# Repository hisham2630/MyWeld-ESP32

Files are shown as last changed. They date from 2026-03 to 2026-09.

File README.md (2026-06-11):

# ⚡ MyWeld ESP32 Firmware

> Supercapacitor spot welder controller firmware for **ESP32-S3** boards — from the **Guition JC3248W535** color touchscreen to **20×4 character LCD** DevKit builds and more.







---

## 📋 Table of Contents

- [Overview](#overview)
- [Hardware](#hardware)
- [Schematic](#-schematic)
- [Architecture](#architecture)
- [Features](#features)
- [Weld Pulse Sequence](#weld-pulse-sequence)
- [BLE Protocol](#ble-protocol)
- [Pin Assignments](#pin-assignments)
- [Supported Boards](#supported-boards)
- [Getting Started](#getting-started)
- [Project Structure](#project-structure)
- [Voice Prompts](#voice-prompts)
- [Configuration](#configuration)
- [Safety Design](#safety-design)
- [Acknowledgments](#acknowledgments)

---

## Overview

**MyWeld** is a DIY supercapacitor spot welder controlled by an ESP32-S3 microcontroller, adapted from the [**MyWeld V2.0 PRO**](https://www.youtube.com/@akakasyan) by **Aka Kasyan**. The firmware provides:

- A full-color touchscreen UI (LVGL 9.x, 480×320) for real-time control and monitoring
- A dual-mode welding engine — **Manual** (button press) and **Auto** (contact detection)
- A **P1 / T / P2 dual-pulse** sequence for professional weld quality
- **BLE companion app** connectivity (Android) via a custom binary protocol
- Up to **10 named presets** stored in NVS (flash)
- **P1/T/P2/P3/P4 quad-pulse** support for advanced weld profiles
- **I2S audio** feedback — TTS voice prompts for boot/BLE, spoken weld warnings, plus tones and melodies with adjustable volume
- Real-time **supercapacitor voltage monitoring** with configurable max voltage (4.0–12.0 V)
- **ADC calibration** system with per-channel correction factors stored in calibration partition

---

## Hardware

| Component | Part |
|---|---|
| **MCU Board** | Guition JC3248W535 (ESP32-S3, 16 MB Flash, PSRAM) |
| **Display** | 3.5″ 480×320 TFT, QSPI, AXS15231B controller |
| **Touch** | Capacitive touch via I2C (addr `0x3B`) |
| **Audio** | Built-in I2S amplifier → speaker (P6 header) |
| **Supercap Bank** | Configurable — supports 4.0–12.0 V (e.g., 2S2P @ 5.7 V or 4S @ 12.0 V) |
| **Gate Driver** | IR4427PBF (half-bridge) or TLP358H(F) (photocoupler) |
| **Output** | MOSFET bank fire signal (`GPIO 46`) |
| **Charger** | Supercap charger enable (`GPIO 16`, active-LOW) |
| **Weld Button** | External trigger (`GPIO 14`, active-LOW, pull-up) |

---

## 🔌 Schematic

Two gate-driver variants are provided — choose the one matching your build:

### Variant A — IR4427 Half-Bridge Gate Driver

<p align="center">
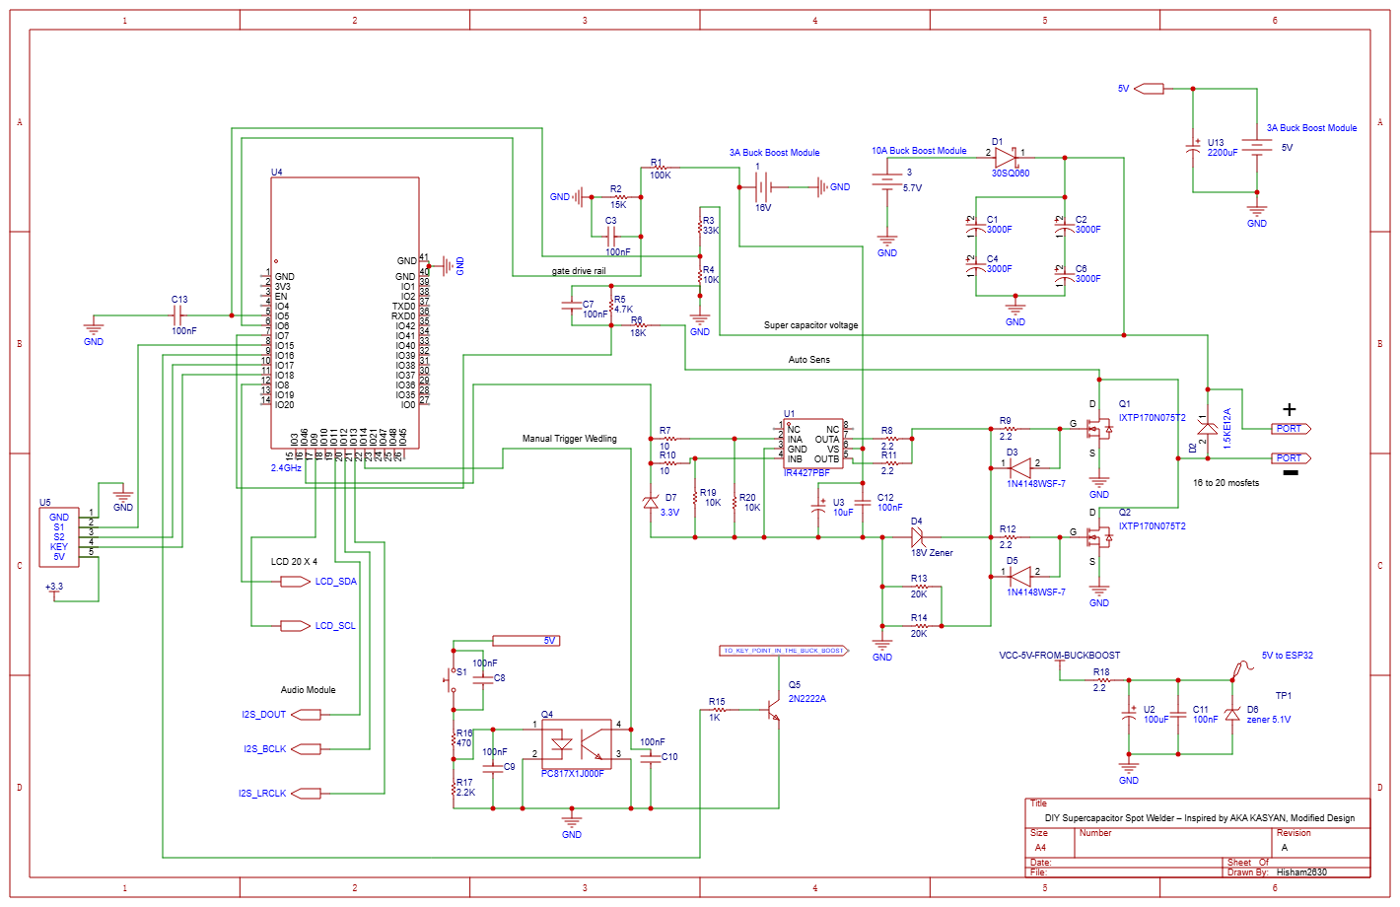
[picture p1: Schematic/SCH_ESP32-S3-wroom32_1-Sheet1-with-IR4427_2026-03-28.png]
MyWeld Schematic — IR4427 Gate Driver
  
</p>

### Variant B — TLP358H(F) Photocoupler Gate Driver

<p align="center">
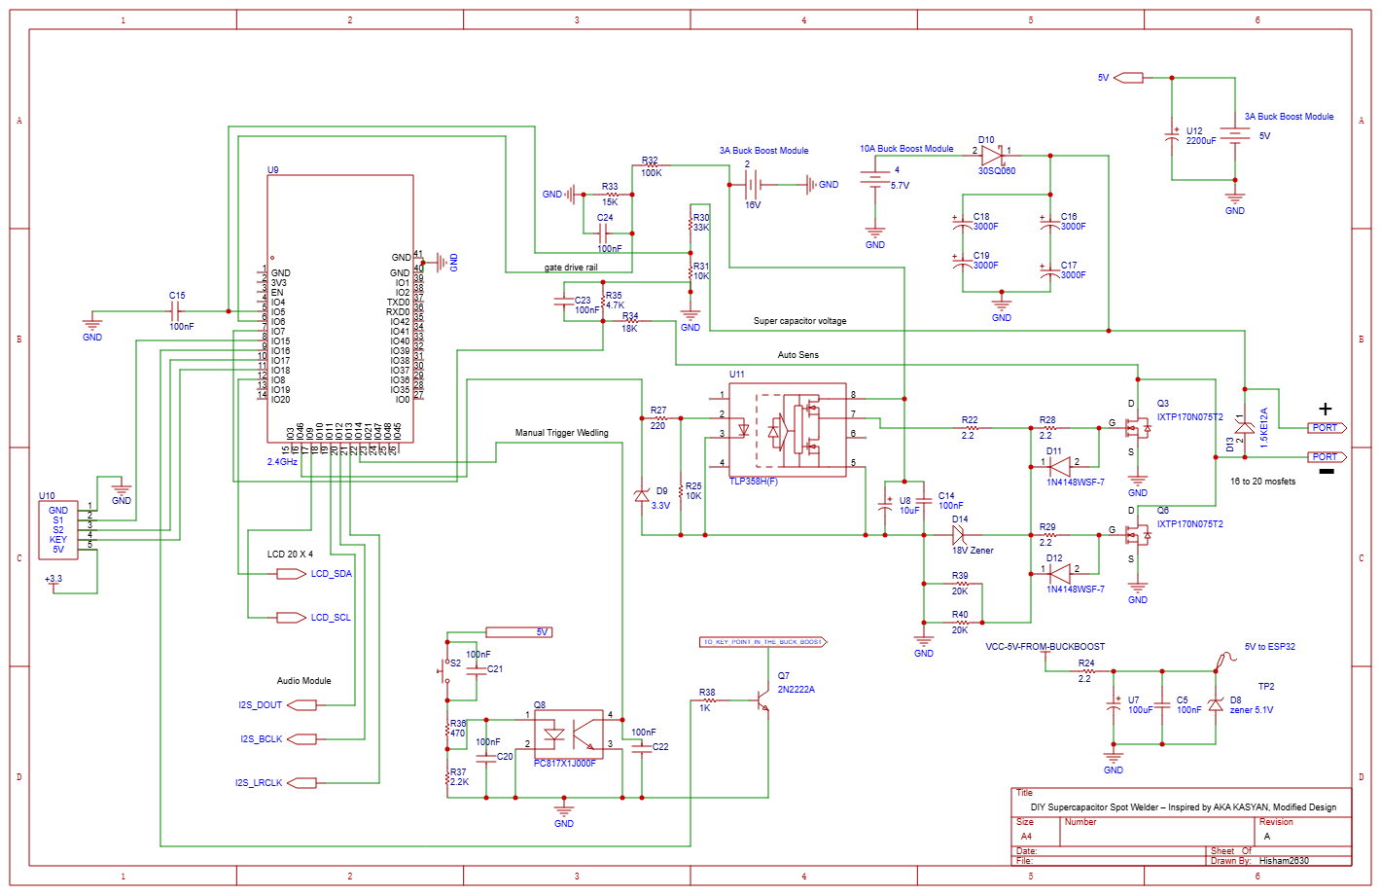
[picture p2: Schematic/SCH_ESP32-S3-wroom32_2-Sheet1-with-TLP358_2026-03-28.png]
MyWeld Schematic — TLP358 Photocoupler
  
</p>

> EasyEDA project files are in the [`Schematic/`](Schematic/) folder.

---

## Architecture

The firmware runs **5 FreeRTOS tasks** pinned to two cores:

```
Core 0                          Core 1
──────────────────────          ────────────────────────────
ui_task      (priority 5)       welding_task  (priority 10)  ← highest
ble_task     (priority 1)       adc_task      (priority  3)
                                audio_task    (priority  2)
```

**Core 0** handles all UI rendering (LVGL) and BLE communication.  
**Core 1** handles time-critical welding pulses, ADC voltage sampling, and audio output.

### Initialization Order (Safety-Critical)

```
1. GPIO safe defaults  ← MOSFET = LOW immediately on boot
2. NVS init           ← Load saved settings / presets
3. I2S audio init
4. Display + LVGL init
5. UI build
6. Welding state machine init
7. BLE serial init
8. Launch FreeRTOS tasks
```

---

## Features

### ✅ Dual Welding Modes

| Mode | Trigger | Description |
|---|---|---|
| **MAN** (Manual) | Physical button (`GPIO 14`) | Press and hold to fire |
| **AUTO** | Electrode contact detection (`GPIO 7`) | Auto-fires after configurable delay `S` |

### ✅ P1/T/P2/P3/P4 Multi-Pulse Sequence

```
[P1] ─ [T] ─ [P2] ─ [T] ─ [P3] ─ [T] ─ [P4]
  │                                        │
0.0–50 ms each         (P2/P3/P4 = 0 → disabled)
```

P3 and P4 are optional additional pulses for advanced weld profiles.

### ✅ Real-Time Status Display

- Supercapacitor voltage bar (0–max V with color coding, configurable max)
- Charge percentage (derived from configurable max voltage)
- Weld state indicator (IDLE / ARMED / FIRING / BLOCKED / ERROR)
- Session and lifetime weld counters
- Active preset name
- Volume level indicator

### ✅ Preset Management

- 20 preset slots — 7 factory (read-only) + 13 user-custom (up to 20 chars each)
- Stores: P1, T, P2, S, mode (AUTO/MAN)
- Instantly loadable from UI or Android app

### ✅ BLE Remote Control

- Device advertises as `"MyWeld"` (configurable display name)
- PIN authentication (default: `1234`)
- Real-time status notifications every ~500 ms
- Read/write all weld parameters remotely
- Load/save presets remotely

### ✅ Audio Feedback

#### Spoken voice prompts (I2S speaker boards)

| Prompt | When |
|---|---|
| **Welcome** | Splash screen phase 1 (boot) |
| **Ready to pair** | Splash finished and BLE advertising |
| **Pairing** | User must enter PIN (1.5 s after connect, or wrong PIN retry) |
| **Device has been connected** | PIN accepted (manual entry or stored PIN auto-auth) |
| **Low charge warning** | Supercap too low to weld |
| **Weak weld warning** | Voltage low but welding still allowed |

Voice clips play first; the startup melody and BLE connect chime still follow where applicable. Buzzer-only boards use distinct tone patterns for the same states.

#### Tones & melodies

| Tone | Event |
|---|---|
| Startup melody (C–E–G) | Boot complete (after welcome voice) |
| Double beep (D5–A5) | BLE authenticated (after connected voice) |
| Single beep (880 Hz) | Parameter changed |
| High beep (1200 Hz) | Pulse fired |
| Error melody | Fault / blocked |
| Contact tone (1000 Hz) | AUTO contact detected |

### ✅ Configurable Supercap Voltage

- Max voltage configurable from **4.0 V to 12.0 V** (step: 0.01 V)
- Stored in calibration partition — survives factory reset
- All thresholds derived automatically:
  - Full = max − 0.2 V
  - Low warning = 70% of max
  - Low block = 50% of max
  - Contact detect = dynamic (based on voltage divider ratio)
- Settable from Android app via BLE calibration command (channel 2)

### ✅ Safety Features

- MOSFET output driven **LOW on boot** before any other init
- Low-voltage block: refuses to weld below **50% of max voltage**
- Low-voltage warning: at **70% of max voltage**
- Charger disabled during pulse (prevents charging during discharge)
- ADC-based protection rail monitoring (gate-drive health check)
- NVS write debouncing (prevents flash wear)
- BLE authentication with **brute-force lockout** (escalating delays)

---

## Weld Pulse Sequence

```
        ┌─ charger OFF ────────────────────────────────────────────────┐
        │  settle 500µs                                                settle 500µs
        │          ┌────┐      ┌────┐      ┌────┐      ┌────┐         │
OUTPUT  │          │ P1 │  T  │ P2 │  T  │ P3 │  T  │ P4 │         │
────────┘          └────┘      └────┘      └────┘      └────┘         └── charger ON
        │←500µs→│← P1→│←T→│← P2→│←T→│← P3→│←T→│← P4→│←500µs→│
```

- **P1**: Pre-pulse (cleans surface, typically 3–8 ms)  
- **T**: Pause between pulses (typically 5–10 ms)  
- **P2**: Main pulse (fuses metal, typically 5–15 ms). Set to 0 for single-pulse mode.
- **P3**: Optional third pulse (set to 0 to disable)
- **P4**: Optional fourth pulse (set to 0 to disable)

---

## BLE Protocol

The firmware uses a custom **binary protocol V2** over BLE GATT.

### GATT Service

| Attribute | UUID |
|---|---|
| Service | `00001234-0000-1000-8000-00805F9B34FB` |
| Params Char (READ) | `00001235-0000-1000-8000-00805F9B34FB` |
| Status Char (NOTIFY) | `00001236-0000-1000-8000-00805F9B34FB` |
| Command Char (WRITE) | `00001237-0000-1000-8000-00805F9B34FB` |

### Packet Format

```
[SYNC=0xAA] [TYPE] [LEN] [PAYLOAD...] [CRC]
                                        └── XOR of TYPE + LEN + all PAYLOAD bytes
```

All multi-byte values are **little-endian**.

### Message Types

| Type | Direction | Description |
|---|---|---|
| `0x01` STATUS | ESP→App | 46-byte periodic status (via NOTIFY, ~500 ms) |
| `0x02` PARAMS_READ | App→ESP | Request current parameters |
| `0x03` PARAMS_RESPONSE | ESP→App | Current parameters (28 bytes) |
| `0x04` PARAMS_WRITE | App→ESP | Update parameters |
| `0x05` CMD | App→ESP | Execute command (sub-typed) |
| `0x06` ACK | ESP→App | Success response |
| `0x07` NAK | ESP→App | Error response |
| `0x08` VERSION | App→ESP | Request firmware version |
| `0x09` VERSION_RESPONSE | ESP→App | Firmware version info |
| `0x0D` AUTH_REQUEST | App→ESP | Authenticate with PIN |
| `0x0E` AUTH_RESPONSE | ESP→App | Authentication result |

### Status Packet (0x01) — 46 bytes

| Offset | Field | Type | Notes |
|---|---|---|---|
| 0 | `supercap_mv` | u16 | Supercap voltage in mV |
| 2 | `protection_mv` | u16 | Gate drive rail in mV |
| 4 | `state` | u8 | Weld state enum |
| 5 | `charge_percent` | u8 | 0–100 % |
| 6 | `auto_mode` | u8 | 0=MAN, 1=AUTO |
| 7 | `active_preset` | u8 | 0–19 (0xFF = user-defined) |
| 8 | `session_welds` | u32 | Session counter |
| 12 | `total_welds` | u32 | Lifetime counter |
| 16 | `ble_connected` | u8 | 1 if BLE connected |
| 17 | `sound_on` | u8 | |
| 18 | `theme` | u8 | 0=dark, 1=light |
| 19 | `error_code` | u8 | 0=none |
| 20 | `p1_x10` | u16 | P1 × 10 (e.g. 50 = 5.0 ms) |
| 22 | `t_x10` | u16 | T × 10 |
| 24 | `p2_x10` | u16 | P2 × 10 |
| 26 | `p3_x10` | u16 | P3 × 10 (0 = disabled) |
| 28 | `p4_x10` | u16 | P4 × 10 (0 = disabled) |
| 30 | `s_x10` | u16 | S × 10 (e.g. 5 = 0.5 s) |
| 32 | `fw_major` | u8 | Firmware major version |
| 33 | `fw_minor` | u8 | Firmware minor version |
| 34 | `volume` | u8 | Master volume 0–100% |
| 35 | `auth_lockout_sec` | u8 | Remaining lockout seconds |
| 36 | `raw_supercap_mv` | u16 | Uncalibrated supercap voltage |
| 38 | `raw_protection_mv` | u16 | Uncalibrated protection voltage |
| 40 | `cal_factor_v_x1000` | u16 | Supercap cal factor × 1000 |
| 42 | `cal_factor_p_x1000` | u16 | Protection cal factor × 1000 |
| 44 | `max_supercap_mv` | u16 | Configured max supercap voltage (mV) |

### Commands (`0x05` CMD sub-types)

| Sub-type | Command |
|---|---|
| `0x01` | Load preset by index |
| `0x02` | Save current params as preset |
| `0x03` | Factory reset |
| `0x04` | Reset weld counter |
| `0x05` | Calibrate ADC (ch0=supercap, ch1=protection, ch2=max voltage) |
| `0x06` | Authenticate (PIN) |
| `0x07` | Change PIN |
| `0x08` | Reboot device |

---

## Pin Assignments

| Function | GPIO | Notes |
|---|---|---|
| MOSFET fire output | 46 | Active HIGH, pull-down |
| Charger enable | 16 | Active LOW |
| Weld button | 14 | Active LOW, pull-up |
| Supercap voltage ADC | 5 | ADC1_CH4, 33k+10k divider |
| Protection rail ADC | 6 | ADC1_CH5, 100k+15k divider |
| Contact detect ADC | 7 | ADC1_CH6, 18k+4.7k divider |
| LCD QSPI CLK | 47 | Internal, no user wiring |
| LCD QSPI CS | 45 | Internal |
| LCD TE | 38 | Internal |
| LCD Backlight | 1 | PWM |
| LCD D0–D3 | 21, 48, 40, 39 | Internal |
| Touch SCL | 8 | I2C |
| Touch SDA | 4 | I2C |
| I2S LRCLK (WS) | 2 | Audio |
| I2S BCLK | 42 | Audio |
| I2S DOUT | 41 | Audio |

---

## Supported Boards

| PlatformIO env | Display | Audio | Notes |
|---|---|---|---|
| `jc3248w535` | 3.5″ 480×320 QSPI TFT + touch (default) | I2S speaker | LVGL UI |
| `jc4827w543` | 4.3″ 480×272 NV3041A + GT911 touch | I2S speaker | LVGL UI, 4 MB flash |
| `esp32s3_lcd2004` | 20×4 character LCD (I2C) | I2S (MAX98357) | No LVGL |
| `esp32s3_st7567s` | 128×64 COG graphic LCD (ST7567S) | I2S speaker | No LVGL |
| `esp32s3_nextion` | Nextion HMI (UART) | I2S speaker | No LVGL |
| `debug` | Same as `jc3248w535` | I2S speaker | Debug symbols, halt-on-panic |

---

## Getting Started

### Prerequisites

- [PlatformIO IDE](https://platformio.org/) (VS Code extension or CLI)
- ESP32-S3 board matching one of the environments above
- USB cable (USB-C)

### Build & Flash

```bash
# Clone the repo
git clone https://github.com/hisham2630/MyWeld-ESP32.git
cd MyWeld-ESP32

# Pick your board environment, e.g.:
pio run -e jc3248w535 --target upload      # Guition 3.5" TFT (default)
pio run -e esp32s3_lcd2004 --target upload # 20×4 LCD DevKit + I2S amp

# Monitor serial output
pio device monitor -e jc3248w535
```

### Debug Build

```bash
# Build with full symbols + halt-on-panic (jc3248w535 base)
pio run -e debug --target upload && pio device monitor -e debug
```

The debug environment uses `-Og` optimisation and `esp32_exception_decoder` for readable backtraces.

---

## Project Structure

```
MyWeld-ESP32/
├── platformio.ini          # Build environments (see Supported Boards)
├── partitions.csv          # Custom 16MB partition table
├── assets/                 # Source WAV clips for embedded voice prompts
├── scripts/
│   ├── embed_wav.py        # WAV → C PCM array embedder
│   └── generate_voice_prompts.py  # TTS generation + embed pipeline
├── DOCS/
│   └── voice-prompts-design.md    # Boot/BLE voice prompt spec
├── Schematic/              # EasyEDA project + schematic images
└── src/
    ├── main.c              # Entry point, task launcher
    ├── boot_audio.c / .h   # Splash + BLE readiness coordination
    ├── config.h            # Pin defs, thresholds, timing constants
    ├── display.c / .h      # QSPI display init, LVGL driver, backlight
    ├── ui.c / .h           # LVGL UI (TFT variants)
    ├── lcd2004.c           # 20×4 character LCD driver
    ├── st7567s.c           # 128×64 COG LCD driver
    ├── nextion.c           # Nextion HMI driver
    ├── welding.c / .h      # Welding state machine + ADC task
    ├── ble_serial.c / .h   # NimBLE GATT server + protocol handler
    ├── audio.c / .h        # I2S tone + voice PCM playback
    ├── buzzer.c            # Passive buzzer backend (tone fallbacks)
    ├── voice_*.c / .h      # Embedded TTS PCM clips
    └── ...
```

---

## Voice Prompts

Boot and BLE lifecycle prompts are pre-generated with **edge-tts**, converted to 44.1 kHz mono PCM, and embedded in flash. See [`DOCS/voice-prompts-design.md`](DOCS/voice-prompts-design.md) for the full trigger map.

### Regenerate clips

Requires Python 3, `edge-tts`, and `ffmpeg` on PATH:

```bash
pip install edge-tts
python scripts/generate_voice_prompts.py
```

This updates `assets/*.wav` and the `src/voice_*.c` embed files. Rebuild firmware afterward.

---

## Configuration

All hardware and behaviour constants are in [`src/config.h`](src/config.h):

| Constant | Default | Description |
|---|---|---|
| `SUPERCAP_V_DEFAULT` | 5.7 V | Default max charge voltage |
| `SUPERCAP_V_MIN` | 4.0 V | Configurable range minimum |
| `SUPERCAP_V_MAX` | 12.0 V | Configurable range maximum |
| `SUPERCAP_V_STEP` | 0.01 V | Adjustment precision |
| `SUPERCAP_V_MULT` | 4.3 | Voltage divider multiplier (33k+10k) |
| `PULSE_MAX_MS` | 50 ms | Maximum pulse duration |
| `S_VALUE_DEFAULT` | 0.5 s | Default AUTO delay |
| `MAX_PRESETS` | 20 | Number of preset slots (7 factory + 13 user) |
| `BLE_DEVICE_NAME` | `"MyWeld"` | Default BLE advertised name |
| `PIN_DEFAULT` | `"1234"` | Factory PIN |
| `NVS_SAVE_DEBOUNCE_MS` | 2000 ms | Flash write debounce |
| `ADC_SAMPLE_INTERVAL` | 500 ms | Voltage sampling interval |

### Derived Thresholds (from `max_supercap_voltage`)

All voltage thresholds are computed dynamically at runtime:

| Threshold | Formula | Example (5.7V) |
|---|---|---|
| Full voltage | `max - 0.2` | 5.5 V |
| Low warning | `max × 0.70` | 3.99 V |
| Low block | `max × 0.50` | 2.85 V |
| Contact detect | `max × R_low/(R_high+R_low) × 0.50` | Dynamic |

---

## Safety Design

> ⚠️ Supercapacitor spot welders store very high energy. The firmware includes multiple safety layers, but improper hardware wiring can still be dangerous. Always verify your hardware before operating.

1. **Boot-time GPIO safety** — `PIN_OUTPUT` is driven LOW **before any `app_main` logic runs** to prevent accidental MOSFET activation during boot.
2. **Voltage blocking** — Welding is hard-blocked when supercap voltage drops below 50% of configured max voltage, preventing weak/incomplete welds.
3. **Protection rail monitoring** — The 13.5 V gate-drive rail is sampled continuously; a fault blocks welding.
4. **Charger interlock** — The charger is disabled during the pulse window to prevent current fighting.
5. **NVS debouncing** — Parameter saves are debounced (`NVS_SAVE_DEBOUNCE_MS`) to reduce flash wear.
6. **BLE authentication** — All parameter writes and commands require PIN authentication with brute-force lockout.
7. **Calibration partition** — Max voltage and ADC cal factors stored in separate NVS partition, surviving factory resets.

---

## Companion App

The Android companion app for remote control is available at:  
👉 **[github.com/hisham2630/MyWeld-Android](https://github.com/hisham2630/MyWeld-Android)**

---

## Acknowledgments

This project is an ESP32-S3 adaptation of the **MyWeld V2.0 PRO** spot welder, originally designed and built by **[Aka Kasyan](https://www.youtube.com/@akakasyan)**.

A huge thank you to Aka Kasyan for:
- 🔩 The original **MyWeld V2.0 PRO** hardware design and PCB layout
- 💻 The proven **welding logic** (dual-pulse P1/T/P2 sequence, protection systems)
- 📺 The excellent **YouTube tutorials** that made this project possible
- 🌍 Sharing his knowledge and inspiring the maker/DIY community

The original project was built around an **Arduino Nano** with a 20×4 LCD, rotary encoder, and 12× IRL40SC228 MOSFETs. This adaptation ports the welding logic to an **ESP32-S3** (Guition JC3248W535) with a full-color TFT touchscreen, BLE companion app, I2S audio, and 16× IXTP170N075T2 MOSFETs — while preserving the core pulse generation and safety principles from Aka Kasyan's original design.

---

## License

This project is open source. See [LICENSE](LICENSE) for details.

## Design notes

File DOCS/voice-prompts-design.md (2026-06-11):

# Boot & BLE Voice Prompts

## Summary

Four TTS spoken prompts give users audible feedback during boot and BLE pairing:

| Prompt | Trigger |
|---|---|
| Welcome | Splash phase 1 (all display variants) |
| Ready to pair | Splash done **and** BLE advertising active |
| Pairing | 1.5 s after BLE connect if still unauthenticated; replay on wrong PIN |
| Device has been connected | PIN auth success (manual or stored PIN auto-auth) |

Voice plays first; existing startup melody and BLE connect chime still follow.

## Assets

- Generated by `scripts/generate_voice_prompts.py` (edge-tts → ffmpeg → `embed_wav.py`)
- Embedded as `voice_welcome`, `voice_ready_to_pair`, `voice_pairing`, `voice_connected`
- Format: 44100 Hz mono s16 PCM (~648 KB total flash)

## Modules

- `boot_audio.c` — coordinates splash + BLE readiness for "ready to pair"
- `audio_play_*()` — I2S PCM on speaker boards; tone fallbacks on buzzer boards
- `ble_serial.c` — pairing timer avoids prompt on fast auto-reconnect

## Regenerating clips

```bash
python scripts/generate_voice_prompts.py
```

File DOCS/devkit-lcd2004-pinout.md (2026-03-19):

# ESP32-S3 DevKit + LCD 2004 — Complete Pin Map

> **Board:** Generic ESP32-S3 N16R8 DevKit-C (`BOARD_VARIANT = 2`)  
> **Display:** 20×4 I2C Character LCD (`DISPLAY_TYPE = 3`)  
> **Audio:** LEDC Buzzer (`AUDIO_TYPE = 2`) or I2S + MAX98357 (`AUDIO_TYPE = 1`)  
> **PlatformIO env:** `devkit_lcd2004`

---

## Master GPIO Table (All Used Pins)

| GPIO | Define | Dir | Category | Function | Wire To |
|---|---|---|---|---|---|
| 0 | — | Input  | System | BOOT button (on-board) | On-board — do not connect |
| 5 | `PIN_VOLTAGE` | Input  | ADC (CH4) | Supercap voltage sense | Voltage divider mid-point (33k+10k)  |
| 6 | `PIN_PROTECTION` | Input  | ADC (CH5) | Gate drive rail voltage sense | Voltage divider mid-point (100k+15k) |
| 7 | `PIN_CONTACT` | Input  | ADC (CH6) | Electrode contact detection | Contact divider mid-point (18k+4.7k) |
| 8 | `PIN_LCD_SDA` | I/O | I2C LCD | I2C Data (SDA) for PCF8574 backpack | LCD backpack SDA |
| 9 | `PIN_LCD_SCL` | Output | I2C LCD | I2C Clock (SCL) for PCF8574 backpack | LCD backpack SCL |
| 9 | `PIN_SPARE_1` | Input  | ADC (CH8) | ⚠️ CONFLICT — reserved for temp sensor | Not usable while LCD I2C is active |
| 11 | `PIN_I2S_DOUT` | Output | Audio (I2S) | I2S Data Out *(only if AUDIO_TYPE=1)* | MAX98357 DIN |
| 12 | `PIN_I2S_BCLK` | Output | Audio (I2S) | I2S Bit Clock *(only if AUDIO_TYPE=1)* | MAX98357 BCLK |
| 13 | `PIN_I2S_LRCLK` | Output | Audio (I2S) | I2S Word Select *(only if AUDIO_TYPE=1)* | MAX98357 LRC |
| 14 | `PIN_START` | Input  | Welding | Weld button — Manual trigger (active LOW, pull-up) | Momentary push button to GND |
| 15 | `PIN_ENC_S1` | Input  | Encoder | Rotary encoder CLK (quadrature A) | Encoder CLK pin |
| 16 | `PIN_CHARGER_EN` | Output | Welding | Supercap charger KEY — HIGH=charge, LOW=off | Charger module KEY/EN pin |
| 17 | `PIN_ENC_S2` | Input  | Encoder | Rotary encoder DT (quadrature B) | Encoder DT pin |
| 18 | `PIN_ENC_KEY` | Input  | Encoder | Rotary encoder push button (active LOW) | Encoder SW pin to GND |
| 19 | — | I/O | System (USB)  | USB JTAG D− (on-board USB-C) | On-board — do not connect |
| 20 | — | I/O | System (USB)  | USB JTAG D+ (on-board USB-C) | On-board — do not connect |
| 26–37| — | — | System | ⛔ Internal Flash/PSRAM — NOT accessible | — |
| 46 | `PIN_OUTPUT` | Output | Welding | 🔥 MOSFET fire signal (gate driver input) | Gate driver IN (opto-coupler/driver) |

> **GPIO46 Safety:** Strapping pin with internal pull-down. Boots LOW before firmware runs = MOSFETs stay OFF at power-on.

---

## Missing: Buzzer Pin (Not Yet Defined for DevKit)

When using `AUDIO_TYPE = AUDIO_BUZZER` (2), there is **no `PIN_BUZZER`
defined** in `board_config.h` for the DevKit variant. You must add one.

**Suggested addition** (choose any free GPIO):

| GPIO | Suggested Define | Function | Notes |
|---|---|---|---|
| 10 | `PIN_BUZZER` | Passive buzzer (LEDC PWM) | Free, ADC1_CH9  |
| 3 | `PIN_BUZZER` | Passive buzzer (LEDC PWM) | Free, ADC1_CH2  |

The GOOUUU CAM variant uses GPIO18 for its buzzer, but on DevKit+LCD that pin is taken by the encoder SW.

---

## Pin Status — Every ESP32-S3 GPIO at a Glance

| GPIO | Status | Used By |
|---|---|---|
| 0 | 🔒 System | BOOT button (on-board) |
| 1 | ✅ Free | Available |
| 2 | ✅ Free | Available |
| 3 | ✅ Free | Available (good for buzzer) |
| 4 | ✅ Free | Available |
| 5 | 🟢 Used | `PIN_VOLTAGE` — ADC supercap |
| 6 | 🟢 Used | `PIN_PROTECTION` — ADC gate rail |
| 7 | 🟢 Used | `PIN_CONTACT` — ADC electrode |
| 8 | 🟢 Used | `PIN_LCD_SDA` — I2C LCD data |
| 9 | 🟢 Used | `PIN_LCD_SCL` — I2C LCD clock |
| 10 | ✅ Free | Available (good for buzzer) |
| 11 | 🟡 Optional  | `PIN_I2S_DOUT` (I2S audio only)  |
| 12 | 🟡 Optional  | `PIN_I2S_BCLK` (I2S audio only)  |
| 13 | 🟡 Optional  | `PIN_I2S_LRCLK` (I2S audio only) |
| 14 | 🟢 Used | `PIN_START` — Weld button |
| 15 | 🟢 Used | `PIN_ENC_S1` — Encoder CLK |
| 16 | 🟢 Used | `PIN_CHARGER_EN` — Charger KEY |
| 17 | 🟢 Used | `PIN_ENC_S2` — Encoder DT |
| 18 | 🟢 Used | `PIN_ENC_KEY` — Encoder SW |
| 19 | 🔒 System | USB JTAG D− |
| 20 | 🔒 System | USB JTAG D+ |
| 21 | ✅ Free | Available |
| 22–25| ✅ Free | Available (check your DevKit) |
| 26–37| ⛔ Reserved  | Flash / PSRAM (not accessible) |
| 38 | ✅ Free | Available |
| 39–45| ✅ Free | Available (check your DevKit) |
| 46 | 🟢 Used | `PIN_OUTPUT` — MOSFET fire |
| 47 | ✅ Free | Available |
| 48 | ✅ Free | Available |

---

## Wiring Diagram

```
ESP32-S3 DevKit-C (N16R8)
┌──────────────────────────────────────────────────────┐
│                                                      │
│  ── WELDING I/O ──                                   │
│  GPIO46 ──────►  Gate Driver IN  (MOSFET fire)       │
│  GPIO16 ──────►  Charger KEY/EN  (charge on/off)     │
│  GPIO14 ◄──────  Weld Button     (to GND, pull-up)   │
│                                                      │
│  ── ADC SENSING ──                                   │
│  GPIO5  ◄──────  Supercap divider (33kΩ + 10kΩ)      │
│  GPIO6  ◄──────  Gate rail divider (100kΩ + 15kΩ)    │
│  GPIO7  ◄──────  Contact divider  (18kΩ + 4.7kΩ)     │
│                                                      │
│  ── I2C LCD (20×4) ──                                │
│  GPIO8  ◄─────►  PCF8574 SDA                         │
│  GPIO9  ──────►  PCF8574 SCL                         │
│                  (I2C addr: 0x27, bus: I2C_NUM_0)    │
│                                                      │
│  ── ROTARY ENCODER ──                                │
│  GPIO15 ◄──────  Encoder CLK                         │
│  GPIO17 ◄──────  Encoder DT                          │
│  GPIO18 ◄──────  Encoder SW  (to GND, pull-up)       │
│                                                      │
│  ── AUDIO (pick one) ──                              │
│  GPIO11 ──────►  MAX98357 DIN   (I2S mode only)      │
│  GPIO12 ──────►  MAX98357 BCLK  (I2S mode only)      │
│  GPIO13 ──────►  MAX98357 LRC   (I2S mode only)      │
│  GPIO??  ─────►  Buzzer         (LEDC mode — TBD)    │
│                                                      │
│  ── SYSTEM (on-board, don't wire) ──                 │
│  GPIO0  ◄──────  BOOT button                         │
│  GPIO19 ◄─────►  USB D−                              │
│  GPIO20 ◄─────►  USB D+                              │
│  GPIO26–37       Flash/PSRAM (inaccessible)          │
│                                                      │
│  ── POWER ──                                         │
│  3V3    ──────►  Encoder VCC, LCD VCC (logic)        │
│  5V     ──────►  LCD backpack VCC (LED backlight)    │
│  GND    ──────►  Common ground (all peripherals)     │
│                                                      │
└──────────────────────────────────────────────────────┘
```

---

## Voltage Divider Reference

| Sensor | R_high  | R_low  | Ratio (Vout/Vin) | Multiplier | Max Input |
|---|---|---|---|---|---|
| Supercap | 33 kΩ | 10 kΩ  | 0.233 | ×4.3 | ~14.1V |
| Gate Rail | 100 kΩ  | 15 kΩ  | 0.130 | ×7.67 | ~25.3V |
| Contact | 18 kΩ | 4.7 kΩ | 0.207 | ×4.83 | ~15.9V |

> All ADC inputs must stay below **3.3V** at the GPIO pin.

---

## Known Conflicts

| GPIO | Issue | Status |
|---|---|---|
| 9 | `PIN_LCD_SCL` vs `PIN_SPARE_1` (temp sensor) | ⚠️ Open — remap if temp sensor needed |
| — | No `PIN_BUZZER` defined for DevKit variant | ⚠️ Open — add GPIO10 or GPIO3 |

---

> **Source files:**  
> [`board_config.h`](../src/board_config.h) — Variant-specific pin overrides  
> [`config.h`](../src/config.h) — Default pin definitions (JC3248W535 baseline)

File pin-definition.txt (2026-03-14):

// P2 8-Pin Header (JC3248W535)
// ─────────────────────────────────────────────────────────────
// Pin 1:  PIN_VOLTAGE     GPIO_NUM_5   // Input  — Supercap voltage ADC1_CH4
// Pin 2:  PIN_PROTECTION  GPIO_NUM_6   // Input  — Gate drive rail ADC1_CH5
// Pin 3:  PIN_CONTACT     GPIO_NUM_7   // Input  — Electrode contact detect ADC1_CH6
// Pin 4:  PIN_ENC_S1      GPIO_NUM_15  // Input  — Encoder CLK quadrature A  ← Encoder
// Pin 5:  PIN_CHARGER_EN  GPIO_NUM_16  // Output — Supercap charger KEY control
// Pin 6:  PIN_OUTPUT      GPIO_NUM_46  // Output — MOSFET bank fire signal
// Pin 7:  PIN_SPARE_1     GPIO_NUM_9   // Free   — Reserved for temp sensor ADC1_CH8
// Pin 8:  PIN_START       GPIO_NUM_14  // Input  — External weld button, MAN mode

// P3/P4 4-Pin Header (JC3248W535) — duplicated headers, same pins
// ─────────────────────────────────────────────────────────────
// Pin 1:  GND                          //        — Ground
// Pin 2:  3V3                          //        — 3.3V power
// Pin 3:  PIN_ENC_S2      GPIO_NUM_17  // Input  — Encoder DT quadrature B   ← Encoder
// Pin 4:  PIN_ENC_KEY     GPIO_NUM_18  // Input  — Encoder push button, LOW  ← Encoder

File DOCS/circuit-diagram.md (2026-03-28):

# MyWeld ESP32-S3 — Circuit Reference

> Board: JC3248W535 · ESP32-S3 N16R8 · Created: 2026-02-26

---

## 1. System Block Diagram

```
                              +13V BATTERY
                                  |
                 +----------------+----------------+
                 |                |                |
            [1A Buck]       [3A Buck]      [10A CC/CV Buck-Boost]
                 |                |                |
              13.5V            5.0V            5.5V / 5A
                 |                |                |
           IR4427/TLP358    ESP32-S3          30SQ060 Schottky
           (Gate Driver)    (via P1 5VIN)          |
                 |                |           SUPERCAPS
            16x MOSFET      Controls:        2S2P 3000F
              Gates         IO46 -> Driver      |
                 |          IO16 -> Charger      |
            16x IXTP        IO14 <- Button       |
            170N075T2       IO5  <- V sense      |
                 |          IO6  <- 13.5V sense  |
                 |          IO7  <- Contact       |
            DRAIN BUS --------- SUPERCAP (+) ----+
                 |
            SOURCE BUS
                 |
            ELECTRODES (+)(-)
                 |
                GND (common)
```

---

## 2. Power Distribution

```
    +13V BATTERY
        |
        +-------> [1A Buck] -------> 13.5V ----> IR4427/TLP358 VDD (always on)
        |
        +-------> [3A Buck] -------> 5.0V  ----> ESP32 P1 +5VIN (always on)
        |
        +-------> [10A Buck-Boost] -> 5.5V ----> 30SQ060 ----> Supercaps
                       |
                      KEY  <--- 2N2222 Collector
                                    |
                                   Base --- 1k --- IO16 (CHARGER_EN)
                                    |
                                 Emitter
                                    |
                                   GND

    Charger Control Truth Table:
    +-----------+-------------+-------------+-----------+
    | IO16      | 2N2222      | KEY Pin     | Charger   |
    +-----------+-------------+-------------+-----------+
    | LOW       | OFF         | Floating    | ON        |
    | HIGH      | ON          | GND         | OFF       |
    +-----------+-------------+-------------+-----------+
```

---

## 3. Supercap Bank (2S2P)

```
    From 30SQ060 Schottky (+)
        |
        +---+------------------+
        |   |                  |
      [3000F 3V]           [3000F 3V]          Parallel pair (top)
      [  Cap 1 ]           [  Cap 2 ]
        |   |                  |
        +---+------ mid ------+
        |   |                  |
      [3000F 3V]           [3000F 3V]          Parallel pair (bottom)
      [  Cap 3 ]           [  Cap 4 ]
        |   |                  |
        +---+------------------+
        |
       GND

    Bank specs:
      Capacitance : 3000F  (series halves, parallel doubles)
      Voltage     : 0-6.0V (2 x 3.0V series)
      Operating   : max 5.7V (derated)
      Energy @5.7V: 48,735 J
      Peak current: ~2000A
```

---

## 4. Gate Drive Circuit

Two gate-driver variants are supported — choose one based on your parts availability:

### Variant A — IR4427PBF Half-Bridge Gate Driver

```
    13.5V (from 1A Buck)
        |
        +--------+---- VDD (pin 8)
        |        |
        |   +---------+
        |   | IR4427   |
        |   |   PBF    |
        |   |          |
        |   | INA   (2)|<--- 10R <--- IO46 (OUTPUT_PIN)
        |   | INB   (4)|---- NC  (channel B unused)
        |   |          |
        |   | OUTA  (7)|---+      (output → gates)
        |   | OUTB  (5)|---- NC  (channel B unused)
        |   |          |
        |   | GND   (3)|
        |   | VS    (6)|
        |   +---------+
        |        |         |
        |       GND        |
        |                  |
        |   1.5KE12A       |
        |   12V TVS        |
        +---|>|<|----------+--- to MOSFET gates via 2R2 each
        |   (bidirectional)|
       GND                 |
                           |
             +-------------+---- GATE BUS
             |
             +-- 2R2 -- Gate Q1  (IXTP170N075T2)
             +-- 2R2 -- Gate Q2
             :          :
             +-- 2R2 -- Gate Q16

    IR4427PBF Pin Wiring:
    +------+--------+-------+------------------------------------------+
    | Pin  | Name   | Wire  | Notes                                    |
    +------+--------+-------+------------------------------------------+
    |  1   | NC     | --    | No connect                               |
    |  2   | INA    | IO46  | Non-inverting input via 10Ω              |
    |  3   | GND    | GND   | Ground                                   |
    |  4   | INB    | NC    | Second channel, not used                 |
    |  5   | OUTB   | NC    | Second channel output, not used          |
    |  6   | VS     | GND   | Auxiliary ground                         |
    |  7   | OUTA   | Gates | Non-inverting output → gate bus          |
    |  8   | VDD    | 13.5V | Gate drive supply                        |
    +------+--------+-------+------------------------------------------+
```

### Variant B — TLP358H(F) Photocoupler Gate Driver

The TLP358H(F) provides **galvanic isolation** between the ESP32 3.3V logic
and the 13.5V gate drive rail. This is preferable in electrically noisy
environments and protects the MCU from gate-side voltage transients.

```
    3.3V (ESP32 side)                 13.5V (Gate drive side)
        |                                  |
       [R27 220Ω]                          +--------+---- VCC (pin 8)
        |                                  |        |
        +--→ Anode (pin 3)   TLP358H(F)    |   +---------+
        |    ░░░░░░░░░░░░░░░░░░░░          |   |         |
  IO46 →|    Cathode (pin 4)  LED → Photo   |   | OUTA (7)|---+
        |    ░░░░░░░░░░░░░░░░░░░░          |   | OUTB (6)|---+
        |                                  |   |         |   |
        |   R25 10k → GND (pin 5 bias)    |   | GND  (5)|   |
        |                                  |   +---------+   |
       GND (ESP32)                        GND (gate side)    |
                                                             |
        1.5KE12A  12V TVS (bidirectional)                    |
        +---|>|<|--------------------------------------------+
        |                                                    |
       GND                                                   |
                                                             |
             +-----------------------------------------------+---- GATE BUS
             |
             +-- 2R2 -- Gate Q3  (IXTP170N075T2)
             +-- 2R2 -- Gate Q5
             :          :
             +-- 2R2 -- Gate Q16

    TLP358H(F) Pin Wiring:
    +------+----------+---------+------------------------------------------+
    | Pin  | Name     | Wire    | Notes                                    |
    +------+----------+---------+------------------------------------------+
    |  1   | NC       | --      | Not connected                            |
    |  2   | NC       | --      | Not connected                            |
    |  3   | Anode    | 220Ω→3V3| LED anode (input side, via R27)          |
    |  4   | Cathode  | IO46    | LED cathode (ESP32 OUTPUT_PIN)           |
    |  5   | GND      | GND     | Output-side ground + bias (R25 10k→GND) |
    |  6   | OUTB     | Gates   | Output B → gate bus (paralleled w/ OUTA) |
    |  7   | OUTA     | Gates   | Output A → gate bus                      |
    |  8   | VCC      | 13.5V   | Gate drive supply                        |
    +------+----------+---------+------------------------------------------+

    Advantage: Full galvanic isolation from ESP32 ← → Gate drive rail
    Note: Both OUTA and OUTB are paralleled for increased drive current
```

### Variant Comparison

| Feature | IR4427PBF | TLP358H(F) |
|---|---|---|
| **Isolation** | None (direct) | ✅ Galvanic (opto)  |
| **Gate drive current** | 1.5A sink/source | ~0.6A (paralleled)  |
| **Input threshold** | TTL compatible | LED forward current |
| **EMI protection** | 10Ω inline | Inherent isolation  |
| **Propagation delay** | ~40 ns | ~0.3 µs |
| **Recommended for** | Simple builds | Noisy environments  |

---

## 5. MOSFET Bank & Welding Output

```
    Supercap (+)
        |
    DRAIN BUS (all 16 drains connected)
        |
    +---+---+---+---+---+--- ... ---+---+
    |   |   |   |   |   |           |   |
    D   D   D   D   D   D           D   D
    |   |   |   |   |   |           |   |
    Q1  Q2  Q3  Q4  Q5  Q6        Q15 Q16   (IXTP170N075T2)
    |   |   |   |   |   |           |   |    75V / 170A / 2.1mR
    S   S   S   S   S   S           S   S
    |   |   |   |   |   |           |   |
    +---+---+---+---+---+--- ... ---+---+
        |
    SOURCE BUS
        |
    WELDING ELECTRODES  (+)  (-)
        |                     |
        +-------[work]--------+
        |
       GND

    Combined Rds(on) = 2.1mR / 16 = ~0.13 mR
    Peak current ~ 2000A (depends on contact resistance)
```

---

## 6. ESP32-S3 I/O Map (JC3248W535)

```
    +----------------------------------------------------------+
    |               JC3248W535  (ESP32-S3 N16R8)                |
    |            16MB Flash QIO  /  8MB PSRAM OPI               |
    |                                                          |
    |  DISPLAY (QSPI, internal)          AUDIO (I2S, internal) |
    |    CLK  = IO47                       LRCLK = IO2         |
    |    CS   = IO45                       BCLK  = IO42        |
    |    TE   = IO38                       DOUT  = IO41        |
    |    D0   = IO21                       -> P6 speaker       |
    |    D1   = IO48                                           |
    |    D2   = IO40                     SD CARD (internal)    |
    |    D3   = IO39                       CLK   = IO12        |
    |    BL   = IO1  (PWM)                 MOSI  = IO11        |
    |                                      MISO  = IO13        |
    |  TOUCH (I2C, internal)               CS    = IO10        |
    |    SCL  = IO8                                            |
    |    SDA  = IO4                                            |
    |    Addr = 0x3B                                           |
    +----------------------------------------------------------+

    P1 Header (UART/Power):
    +------+------+------+------+
    | 5VIN |  TXD |  RXD |  GND |
    +------+------+------+------+

    P2 Header (User I/O):
    +------+------+------+------+------+------+------+------+
    | IO5  | IO6  | IO7  | IO15 | IO16 | IO46 | IO9  | IO14 |
    | pin1 | pin2 | pin3 | pin4 | pin5 | pin6 | pin7 | pin8 |
    +------+------+------+------+------+------+------+------+
      |      |      |      |      |      |      |      |
      V_sns  P_sns  C_det ENC_S1 CHG_EN OUTPUT Spare  BTN

    P3/P4 Headers (duplicated):       P5 (Battery):
    +------+------+------+------+     +------+------+
    |  GND | 3.3V | IO17 | IO18 |     | -VAT | +VAT |
    +------+------+------+------+     +------+------+
                   ENC_S2 ENC_KEY      DO NOT use for 13V!
```

---

## 7. ADC Voltage Dividers

```
    A) SUPERCAP VOLTAGE (IO5 / ADC1_CH4)

        Supercap (+)
            |
           10k  R1
            |
            +-------> IO5
            |
           15k  R2
            |
           GND

        Ratio  = 15 / (10+15) = 0.600
        @5.7V  = 3.42V at ADC (11dB atten)
        Formula: V_real = V_adc x (25/15)

    B) PROTECTION RAIL (IO6 / ADC1_CH5)

        Gate Drive Rail (13.5V nominal, safe up to ~25V)
            |
           100k  R1
            |
            +-------> IO6
            |
           15k  R2
            |
           GND

        Ratio  = 15 / (100+15) = 0.130
        @13.5V = 1.76V at ADC (plenty of headroom)
        @18V   = 2.35V at ADC (safe)
        @24V   = 3.13V at ADC (safe)
        @25.3V = 3.30V at ADC (absolute ceiling)
        Formula: V_real = V_adc x (115/15)

    C) CONTACT DETECT (IO7 / ADC1_CH6)

        Electrode tip
             |
            4.7k  (isolation from welding transients)
             |
             +-------> IO7
             |
            5.1k  (to GND)
             |
            GND

        Apart: IO7 ~ 0V    (no current path, 5.1k pulls to GND)
        Touch: IO7 rises    (supercap V feeds through workpiece → 4.7k/5.1k divider)
        Threshold: 1.5V     (contact_detected = v_contact > 1.5V)

        Divider ratio = 5.1 / (4.7 + 5.1) = 0.520
        @3.0V cap = 1.56V at IO7  (just above threshold — matches LOW_VOLTAGE_BLOCK)
        @5.5V cap = 2.87V at IO7  (safe)
        @5.7V cap = 2.97V at IO7  (safe, well below 3.3V max)

        Note: Original Kasyan used 10k (Arduino 5V tolerant).
              Reduced to 5.1k for ESP32 3.3V ADC headroom.
```

---

## 8. Weld Button

```
        3.3V (internal pull-up)
         |
        [R]  internal pull-up
         |
         +-------> IO14 (START_PIN)
         |
        [NO]  momentary button
         |
        GND

    Released: IO14 = HIGH
    Pressed : IO14 = LOW
    Debounce: 5ms

    SAFETY: Only physical button can fire in MAN mode.
            BLE alone cannot trigger a weld.
            Touchscreen has NO weld button.
```

---

## 9. Pulse Timing

```
    CHARGER_EN   ____/````````````````````````````````````\____
    (IO16)            |<-- charger OFF during pulse -->|

    OUTPUT_PIN   ________/`````\__________/`````\_____________
    (IO46)               | P1  |   T      | P2  |

                    500us  P1     T (pause)  P2    500us
                   settle                         settle

    +--------+---------+-------+
    | Param  | Range   | Step  |
    +--------+---------+-------+
    | P1     | 0-50 ms | 0.5ms |
    | T      | 0-50 ms | 0.5ms |
    | P2     | 0-50 ms | 0.5ms |  (P2=0 means single pulse)
    +--------+---------+-------+

    Example "0.15mm Nickel": P1=5ms, T=8ms, P2=8ms
    Timing engine: ets_delay_us() (microsecond precision)
```

---

## 10. BLE Architecture

```
    ESP32-S3 (NimBLE)                     Android App (Nordic BLE)
    +------------------------+            +------------------------+
    |  Service: 0x1234       |            |  MyWeld-Android        |
    |                        |            |  Jetpack Compose       |
    |  Params  (0x1235) R/W  |<-- bin --> |  Read/Write params     |
    |  Status  (0x1236) R/N  |--- bin --> |  Live dashboard        |
    |  Command (0x1237) W    |<-- bin --- |  OTA, reboot, cal      |
    |                        |            |                        |
    |  PIN Auth: "1234"      |            |                        |
    |  Max tries: 5          |            |                        |
    |  Lockout: 60s          |            |                        |
    +------------------------+            +------------------------+
```

---

## 11. FreeRTOS Tasks

```
    +--- CORE 0 -------------------------+--- CORE 1 -----------------------+
    |                                     |                                  |
    |  UI Task                            |  Welding Task                    |
    |    Priority : 5                     |    Priority : 10 (HIGHEST)       |
    |    Stack    : 20 KB                 |    Stack    : 4 KB               |
    |    Job      : LVGL render, touch    |    Job      : State machine,     |
    |                                     |              pulse gen,          |
    |  BLE Task                           |              protection checks   |
    |    Priority : 1                     |                                  |
    |    Stack    : 4 KB                  |  ADC Task                        |
    |    Job      : NimBLE GATT,          |    Priority : 3                  |
    |              params, OTA            |    Stack    : 4 KB               |
    |                                     |    Job      : Voltage sampling   |
    |                                     |              every 500ms         |
    |                                     |                                  |
    |                                     |  Audio Task                      |
    |                                     |    Priority : 2                  |
    |                                     |    Stack    : 4 KB               |
    |                                     |    Job      : I2S tone output    |
    +-------------------------------------+----------------------------------+

    Design: Welding @ Core1 Priority10 = never interrupted during pulse.
```

---

## 12. Weld Cycle Signal Flow

```
    Button pressed (IO14 = LOW)
        |
        v
    Check protection rail (IO6) -- FAIL --> Block + error tone
        |
        OK
        v
    Check supercap voltage (IO5) -- < 3.0V --> Block + warning
        |
        OK (> 3.0V)
        v
    CHARGER_EN = HIGH (IO16) -----> 2N2222 ON --> Charger OFF
        |
    wait 500us (settle)
        |
        v
    OUTPUT_PIN = HIGH (IO46) -----> IR4427/TLP358 ---> 16x MOSFET ON
        |                                           Supercap -> Electrodes
    wait P1 (us precision)                          ~2000A pulse
        |
        v
    OUTPUT_PIN = LOW ----------------> MOSFETs OFF
        |
    wait T (pause)
        |
        v
    OUTPUT_PIN = HIGH ---------------> MOSFETs ON (2nd pulse)
        |
    wait P2
        |
        v
    OUTPUT_PIN = LOW ----------------> MOSFETs OFF
        |
    wait 500us (settle)
        |
        v
    CHARGER_EN = LOW (IO16) ------> 2N2222 OFF --> Charger ON
        |
        v
    playWeldFire() --> I2S --> Speaker
    weldCount++
    Update UI voltage bar
    BLE status notify --> Android app
```

---

## 13. Safety Interlocks Summary

```
    +----+---------------------------+------------+------------------+
    | #  | Check                     | Threshold  | Action           |
    +----+---------------------------+------------+------------------+
    | 1  | Supercap voltage LOW      | < 4.0V     | UI warning       |
    | 2  | Supercap voltage CRITICAL | < 3.0V     | Block welding    |
    | 3  | Gate drive rail LOW       | < 10V      | Block welding    |
    | 4  | Gate drive rail HIGH      | > 18V      | Block welding    |
    | 5  | Gate drive not connected  | < 8V       | Bench mode (OK)  |
    | 6  | OTA update in progress    | --         | Block welding    |
    | 7  | IO46 at boot              | --         | Forced LOW       |
    | 8  | IO16 at boot              | --         | Forced LOW       |
    | 9  | MAN mode trigger          | --         | Physical btn only|
    | 10 | Confirmation time         | 1500ms     | Debounce faults  |
    +----+---------------------------+------------+------------------+
```

---

## 14. Component BOM

| #  | Component | Part / Value | Qty | Notes |
|----|---|---|-----|---|
| 1  | MCU Board | JC3248W535 | 1 | ESP32-S3 + display + touch |
| 2  | MOSFET | IXTP170N075T2 | 16  | 75V 170A 2.1mΩ TO-220 |
| 3  | Gate Driver (Opt A) | IR4427PBF | 1 | Half-bridge, single ch (OUTA) |
| 3b | Gate Driver (Opt B) | TLP358H(F) | 1 | Photocoupler (galvanic isolation) |
| 4  | Gate Resistors | 2.2Ω | 16  | One per MOSFET gate |
| 4a | Input Protection R | 10Ω (IR4427) or 220Ω (TLP358) | 1 | IO46 → driver input |
| 4b | Bias Resistor | 10kΩ (TLP358 only)  | 1 | TLP358 pin 5 bias to GND |
| 5  | TVS Diode | 1.5KE12A | 1 | 12V bidirectional |
| 6  | Charger Module | 10A CC/CV Buck-Boost| 1 | Set 5.5V / 5A |
| 7  | Schottky Diode | 30SQ060 | 1 | 60V 30A reverse blocking |
| 8  | Transistor | 2N2222 | 1 | KEY pin isolation |
| 9  | Base Resistor | 1kΩ | 1 | IO16 to 2N2222 base |
| 10 | Logic Buck | 3A Buck Module | 1 | 13V → 5.0V for ESP32 |
| 11 | Gate Buck | 1A Buck Module | 1 | 13V → 13.5V for gate driver  |
| 12 | Supercaps | 3.0V 3000F | 4 | 2S2P configuration |
| 13 | V-Divider R1 | 10kΩ | 1 | Supercap sense |
| 14 | V-Divider R2 | 15kΩ | 1 | Supercap sense |
| 15 | P-Divider R1 | 100kΩ | 1 | Protection rail sense |
| 16 | P-Divider R2 | 15kΩ | 1 | Protection rail sense |
| 17 | Contact Isolation | 4.7kΩ | 1 | Electrode tip to IO7 |
| 18 | Contact Pull-down | 5.1kΩ | 1 | IO7 to GND |
| 19 | Battery | 13V Lead-Acid | 1 | External power |
| 20 | Weld Button | Momentary NO | 1 | Physical trigger |
| 21 | Speaker | 8Ω small | 1 | Connects to P6 |
| 22 | Rotary Encoder | KY-040 module | 1 | 5-pin: 5V, S1(IO15), S2(IO17), KEY(IO18), GND |

---

> ⚠️ **DANGER:** ~2000A peak / ~49kJ stored. Discharge supercaps before servicing.

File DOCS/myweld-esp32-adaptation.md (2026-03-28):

# MyWeld ESP32-S3 JC3248W535 Adaptation

## Goal
Adapt the MyWeld V2.0 PRO Arduino Nano spot welder code to run on the **JC3248W535** (ESP32-S3 + 480×320 TFT capacitive touch) with a full dashboard UI using **LovyanGFX + LVGL**, preserving all original welding logic while adding enhanced features.

---

## Decisions Summary

| Decision | Choice |
|---|---|
| **Framework** | **PlatformIO + ESP-IDF 5.x** — proven to work with JC3248W535/AXS15231B |
| **LVGL** | **v9.x** — latest API, active development |
| **UI Style** | **Full Dashboard** — all parameters + voltage bar + status on one rich screen |
| **Theme** | **Dark mode + Light mode** — switchable in settings |
| **MAN Weld Trigger** | **Physical button only** (IO14) — safety-first for 2000A system |
| **Charger Control** | **Dedicated CHARGER_EN** (IO16) — independent timing control |
| **Display Library** | **LovyanGFX + LVGL 9.x** — fast rendering + rich widget toolkit |
| **Encoder** | **REMOVED** — all parameter adjustment via touchscreen |
| **Audio** | **I2S speaker** via built-in amp — pleasant tones, not buzzer |
| **Pulse Resolution** | **0.5ms steps** (0, 0.5, 1.0, 1.5, ... 50ms) |
| **Bluetooth** | **BLE serial** — phone monitoring & parameter control |
| **Language** | English only |
| **Extra Features** | ALL: live voltage graph, weld counter, preset profiles (10 slots), color voltage bar, charging animation, settings page, ADC calibration, test mode |

---

## Hardware Changes from Original V2.0 PRO

| Original | Replacement |
|---|---|
| Arduino Nano | JC3248W535 (ESP32-S3-WROOM-1, N16R8) |
| 20×4 I2C LCD | Built-in 480×320 TFT (AXS15231B driver, QSPI) |
| Rotary Encoder + Push Button | Capacitive touchscreen |
| EEPROM | NVS (Preferences library) |
| 12× IRL40SC228 MOSFETs | 16× IXTP170N075T2 MOSFETs |
| TC4422CPA gate driver | IR4427PBF or TLP358H(F) (galvanic isolation variant) |
| TPS61088 boost | 10A CC/CV buck-boost module (supercap charger, KEY pin for EN) |
| 7805 regulator | 3A buck-boost → 5V (logic), 1A buck → 13.5V (gate drive) |
| SMCJ13A TVS | 1.5KE12A 12V bidirectional TVS |
| Gate resistors 4R7 | 2.2Ω per MOSFET |
| Supercap-powered logic | External 13V battery |
| — | 30SQ060 Schottky diode on charger output |
| — | 2N2222 transistor for KEY pin isolation |

---

## JC3248W535 Board Pin Assignments (VERIFIED ✅)

> Source: Official JC3248W535 GPIO割当表 (2025/02/01)

### Display (QSPI — internal, no user wiring)
| Function | GPIO |
|---|---|
| CLK | 47 |
| CS | 45 |
| DC (RS) | NC |
| RST | NC |
| TE | 38 |
| BL (Backlight PWM) | 1 |
| DATA0 | 21 |
| DATA1 | 48 |
| DATA2 | 40 |
| DATA3 | 39 |

### Touch (I2C — internal, from schematic)
| Function | GPIO |
|---|---|
| I2C SCL (TP_SCL) | 4 |
| I2C SDA (TP_SDA) | 8 |
| RST | NC (not connected) |
| INT | NC (not connected) |
| I2C Address | 0x3B |

> ⚠️ **Note:** The GPIO allocation table labels these as SDA=4/SCL=8, but the **schematic** clearly shows IO4→TP_SCL and IO8→TP_SDA. The schematic is the source of truth. In ESP32-S3 code, we configure with `Wire.begin(/*SDA=*/8, /*SCL=*/4)`.

### I2S Audio (built-in amplifier → P6 speaker connector)
| Function | GPIO |
|---|---|
| CTRL (amp power) | VBAT (always on) |
| LRCLK (Word Select) | **2** |
| BCLK (Bit Clock) | **42** |
| DATA (I2S Data Out) | **41** |

> 🔊 **The board has a built-in I2S audio amplifier!** Connect a small speaker to **P6** (-SP, -VAT). This replaces the ugly buzzer with proper audio tones/melodies.

> ⚠️ **GPIO2, GPIO41, GPIO42 are NOT available as user IO** — they are wired to the I2S audio system.

### SD Card (TF slot — internal)
| Function | GPIO |
|---|---|
| CLK | 12 |
| MOSI (CMD) | 11 |
| MISO (DAT0) | 13 |
| CS (CD/DAT3) | 10 |

> ⚠️ **GPIO 10, 11, 12, 13 are used by SD card** — NOT available for general IO even though they appear similar to user GPIOs.

### Board Connectors Reference
| Connector | Pin 1 | Pin 2 | Pin 3 | Pin 4 | Pin 5 | Pin 6 | Pin 7 | Pin 8 |
|---|---|---|---|---|---|---|---|---|
| **P1** (UART/Power) | +5VIN | TXD | RXD | GND | — | — | — | — |
| **P2** (8P User IO) | IO5 | IO6 | IO7 | IO15 | IO16 | IO46 | IO9 | IO14 |
| **P3** (4P IO) | GND | 3.3V | IO17 | IO18 | — | — | — | — |
| **P4** (4P IO) | GND | 3.3V | IO17 | IO18 | — | — | — | — |
| **P5** (Battery) | -VAT | +VAT | — | — | — | — | — | — |
| **P6** (Speaker) | -SP | -VAT | — | — | — | — | — | — |

> P3 and P4 are **duplicates** — both expose IO17 and IO18.

### Switches
| Switch | Action |
|---|---|
| **SW1** single press | ON |
| **SW1** double press | OFF |
| **RST** | Reset |
| **BOOT** | Boot mode |

### User GPIO Assignment for MyWeld (P2 header)
| Function | GPIO | Header Pin | Direction | ADC? | Notes |
|---|---|---|---|---|---|
| **OUTPUT_PIN** (MOSFET fire) | **IO46** | P2 pin 6 | Digital OUT | No | Pure digital, no ADC conflict |
| **CHARGER_EN** | **IO16** | P2 pin 5 | Digital OUT | — | KEY pin control via 2N2222 |
| **START_PIN** (Weld button) | **IO14** | P2 pin 8 | INPUT_PULLUP | — | External physical weld trigger |
| **VOLTAGE_PIN** (Supercap V) | **IO5** | P2 pin 1 | ADC Input | ADC1_CH4 ✓ | Via 33k/10k divider (supports 4.0–12.0V) |
| **PROTECTION_PIN** (13.5V) | **IO6** | P2 pin 2 | ADC Input | ADC1_CH5 ✓ | Via 100k/15k divider |
| **CONTACT_PIN** (Auto mode) | **IO7** | P2 pin 3 | ADC Input | ADC1_CH6 ✓ | Via 18k/4.7k divider |
| **SPEAKER** (I2S audio) | **IO2/42/41** | Built-in | I2S Output | — | Built-in amp → P6 speaker |
| *Spare* | **IO15** | P2 pin 4 | — | ADC2_CH4 | Available for future use |
| *Spare* | **IO9** | P2 pin 7 | — | ADC1_CH8 | Available for future use |
| *Spare* | **IO17** | P3/P4 | — | ADC2_CH6 | Available for future use |
| *Spare* | **IO18** | P3/P4 | — | ADC2_CH7 | Available for future use |

> ✅ All 3 ADC inputs use **ADC1** channels (GPIO5, 6, 7) — most reliable, no WiFi conflict.

> ✅ **4 spare GPIOs** remain (IO9, IO15, IO17, IO18) for future expansion.

### ADC Voltage Divider Calculations (3.3V ESP32-S3 ADC)

| Measurement | Range | Divider | ADC Voltage | Multiplier |
|---|---|---|---|---|
| Supercap (4.0–12.0V) | 33k/10k | 0–2.79V @12V | Safe ✓ | `V = ADC_raw × (3.3/4095) × 4.3` |
| Protection (0–13.5V) | 100k/15k | 0–1.76V | Safe ✓ | `V = ADC_raw × (3.3/4095) × 7.667` |
| Contact detect | 18k/4.7k | 0–1.5V @12V | Safe ✓ | Dynamic threshold (50% of expected) |

---

## Power Architecture

```
13V External Battery
    │
    ├──→ [1A Buck Module] ──→ 13.5V ──→ IR4427/TLP358 VDD (gate drive, ALWAYS ON)
    │
    ├──→ [3A Buck Module] ──→  5.0V ──→ ESP32-S3 via P1 +5VIN (ALWAYS ON)
    │
    └──→ [10A CC/CV Buck-Boost] ──→ Configurable V (4.0–12.0V) ──→ [30SQ060 Schottky] ──→ Supercaps (bank config varies)
                │                                                             │
               KEY pin ←── 2N2222 collector                                   │
                             │ base ← [1kΩ] ← IO16 (CHARGER_EN)              ↓
                            │ emitter ← GND                            MOSFET Bank (16× IXTP170N075T2)
                                                                              │
                                                                        Welding Output
```

### Disconnect Logic
- `CHARGER_EN = LOW` (idle) → transistor OFF → KEY floating → module ON → charging ✓
- `CHARGER_EN = HIGH` (weld) → transistor ON → KEY pulled to GND → module OFF → clean pulse ✓

---

## Software Architecture (PlatformIO + ESP-IDF 5.x)

```
MyWeld-ESP32/
├── platformio.ini                # Build config: ESP32-S3, ESP-IDF 5.x, LVGL 9.x
├── sdkconfig.defaults            # ESP-IDF defaults (PSRAM, flash, I2S, etc.)
├── main/
│   ├── CMakeLists.txt
│   ├── main.c                    # Entry point: app_main()
│   ├── config.h                  # Pin definitions, constants, thresholds
│   ├── display.h / display.c     # LovyanGFX init + LVGL flush/input bridge
│   ├── ui.h / ui.c               # LVGL UI: screens, widgets, callbacks
│   ├── ui_theme.h / ui_theme.c   # Dark/Light mode theme definitions
│   ├── welding.h / welding.c     # Core welding logic (pulse, protection, contact)
│   ├── audio.h / audio.c         # I2S audio: tones, melodies, feedback
│   ├── settings.h / settings.c   # NVS read/write, preset profiles
│   ├── ble_serial.h / ble_serial.c # Bluetooth LE serial (phone control)
│   └── lv_conf.h                 # LVGL 9.x configuration
├── components/                   # ESP-IDF custom components if needed
│   └── lovyangfx/                # LovyanGFX as component
└── boards/
    └── jc3248w535.json            # Custom board definition
```

> **Why ESP-IDF instead of Arduino?** The AXS15231B display on JC3248W535 requires ESP-IDF 5.x I2C/SPI drivers that Arduino-ESP32 doesn't fully support yet. NorthernMan54's proven build uses ESP-IDF 5.3. We use C (not C++) for ESP-IDF consistency, but LovyanGFX is C++ — we wrap it.

### Core Modules

#### 1. `config.h` — Pin Definitions & Constants
```c
// GPIO Pins (JC3248W535 — VERIFIED from official pinout table + schematic)
#define OUTPUT_PIN      46   // MOSFET bank fire signal (P2 pin 6)
#define CHARGER_EN      16   // Supercap charger KEY control (P2 pin 5)
#define START_PIN       14   // Physical weld button, MAN mode (P2 pin 8)
#define VOLTAGE_PIN     5    // Supercap voltage ADC — ADC1_CH4 (P2 pin 1)
#define PROTECTION_PIN  6    // 13.5V rail protection ADC — ADC1_CH5 (P2 pin 2)
#define CONTACT_PIN     7    // Electrode contact detection ADC — ADC1_CH6 (P2 pin 3)
#define BACKLIGHT_PIN   1    // Display backlight PWM (built-in)

// I2S Audio (built-in amplifier → speaker on P6)
#define I2S_LRCLK       2    // I2S Word Select (WS)
#define I2S_BCLK        42   // I2S Bit Clock
#define I2S_DATA        41   // I2S Data Out

// Touch I2C (from schematic: IO4=SCL, IO8=SDA)
#define TOUCH_SCL       4
#define TOUCH_SDA       8

// ADC
#define ADC_RESOLUTION  12   // ESP32-S3: 12-bit (0–4095)
#define ADC_VREF        3.3f

// Voltage divider multipliers
#define SUPERCAP_V_MULT     4.3f          // 33k+10k divider
#define PROTECTION_V_MULT   7.667f        // 100k+15k divider

// Supercap Bank (configurable)
#define SUPERCAP_V_DEFAULT      5.7f   // Default max charge voltage
#define SUPERCAP_V_MIN          4.0f   // Configurable range minimum
#define SUPERCAP_V_MAX          12.0f  // Configurable range maximum
#define SUPERCAP_V_STEP         0.01f  // Adjustment precision
// Derived thresholds (from max_supercap_voltage at runtime):
//   Full    = max - 0.2V
//   Warning = max × 70%
//   Block   = max × 50%
//   Contact = dynamic (based on divider ratio)

// Protection thresholds
// Contact threshold is dynamically calculated from max_supercap_voltage
#define PROTECTION_LOW          10.0f  // Gate drive rail min (V)
#define PROTECTION_HIGH         18.0f  // Gate drive rail max (V)

// Pulse parameters
#define PULSE_MIN_MS            0.0f   // Minimum pulse (0 = OFF for P2)
#define PULSE_MAX_MS            50.0f  // Maximum pulse duration
#define PULSE_STEP_MS           0.5f   // Step size (0.5ms resolution)
#define S_VALUE_MIN             0.3f   // AUTO mode: min contact delay (s)
#define S_VALUE_MAX             2.0f   // AUTO mode: max contact delay (s)
#define S_VALUE_STEP            0.1f   // AUTO mode: step size (s)

// Timing
#define DEBOUNCE_DELAY_MS       5
#define LOW_V_CONFIRM_MS        1500
#define PROTECTION_CONFIRM_MS   1500
#define CHARGER_SETTLE_US       500    // Settle time before/after pulse
```

#### 2. `welding.c` — Core Logic
- `generatePulse()` — P1/T/P2/P3/P4 multi-pulse with CHARGER_EN disconnect
- `checkProtectionVoltage()` — 13.5V rail monitoring
- `checkContactDetection()` — AUTO mode electrode sensing (dynamic threshold)
- `checkLowVoltage()` — Supercap voltage protection (configurable threshold)
- All voltage thresholds use `settings_get_*()` dynamic getters

#### 2b. `audio.cpp` — I2S Audio Feedback (NEW — replaces buzzer)
- Uses ESP32-S3 I2S peripheral → built-in amplifier → speaker on P6
- `playTone(freq, duration)` — generate sine wave at given frequency
- `playBeep()` — short confirmation beep (pleasant tone, not harsh buzzer)
- `playWeldReady()` — ascending 2-note chime when caps fully charged
- `playWeldFire()` — short sharp tone when pulse fires
- `playError()` — descending warning tone for protection alerts
- `playStartup()` — boot-up melody (3–4 notes)
- Sound can be muted via settings toggle

#### 3. `ui.cpp` — LVGL Dashboard (New)

**Main Dashboard Screen Layout (480×320):**
```
┌─────────────────────────────────────────────────────┐
│  ⚡ MyWeld ESP32              🔋 13.2V    AUTO/MAN  │  ← Status bar
├─────────────────────────────────────────────────────┤
│                                                     │
│   ┌─────────┐  ┌─────────┐  ┌─────────┐           │
│   │  P1     │  │   T     │  │  P2     │           │
│   │  15ms   │  │  10ms   │  │  20ms   │           │  ← Tap to edit
│   │  [−][+] │  │  [−][+] │  │  [−][+] │           │  ← Touch +/- buttons
│   └─────────┘  └─────────┘  └─────────┘           │
│                                                     │
│  S = 0.5s (AUTO only)  [−][+]                      │
│                                                     │
│  ┌────────────────────────────────────────────────┐ │
│  │  ████████████████████░░░░░░  4.8V / 5.4V  92% │ │  ← Color voltage bar
│  └────────────────────────────────────────────────┘ │
│                                                     │
│  ┌────────────────────────────────────────────────┐ │
│  │  Voltage History Graph (last 30 seconds)       │ │  ← Live voltage graph
│  └────────────────────────────────────────────────┘ │
│                                                     │
│  Welds: 42 (session) / 1,247 (total)    ⚙️ [MENU]  │  ← Weld counter + settings
│  Status: READY ● (charging animation)              │  ← Status indicator
└─────────────────────────────────────────────────────┘
```

**Settings Screen (slide-in or new screen):**
- Brightness slider (0–100%)
- Sound ON/OFF toggle
- AUTO/MAN mode switch
- S value adjustment (AUTO mode only, 0.3–2.0s)
- Preset profiles: Save/Load (up to 5 named presets)
- Weld counter reset
- About / version info

**Preset Profile Structure (NVS):**
```c
#define MAX_PRESETS 10

typedef struct {
    char name[20];      // e.g. "0.15mm Nickel"
    float p1;           // 0–50 ms (0.5ms steps)
    float t;            // 0–50 ms (0.5ms steps)
    float p2;           // 0–50 ms (0 = OFF, 0.5ms steps)
    float sValue;       // 0.3–2.0s (AUTO mode delay)
    bool autoMode;
} weld_preset_t;
```

**Factory Default Presets:**
| # | Name | P1 | T | P2 | Auto S | Notes |
|---|---|-----|-----|-----|---|---|
| 0 | 0.1mm Nickel | 3.0 | 5.0 | 5.0 | 0.5s | Thin battery tabs |
| 1 | 0.15mm Nickel | 5.0 | 8.0 | 8.0 | 0.5s | Standard tabs |
| 2 | 0.2mm Nickel | 8.0 | 10.0 | 12.0 | 0.5s | Thick tabs |
| 3 | 0.3mm Nickel | 12.0 | 12.0 | 18.0 | 0.6s | Heavy duty |
| 4 | 0.5mm Nickel | 18.0 | 15.0 | 25.0 | 0.8s | Busbar connections |
| 5 | Stainless Steel | 20.0 | 15.0 | 30.0 | 0.8s | Higher resistance |
| 6 | Aluminum | 25.0 | 12.0 | 35.0 | 0.8s | Oxide layer needs energy |
| 7 | Custom 1 | 10.0 | 10.0 | 10.0 | 0.5s | User-defined |
| 8 | Custom 2 | 10.0 | 10.0 | 10.0 | 0.5s | User-defined |
| 9 | Custom 3 | 10.0 | 10.0 | 10.0 | 0.5s | User-defined |

> ⚠️ Preset values are starting points — users MUST tune for their specific electrodes, cable resistance, and supercap charge level.

#### 4. `settings.c` — NVS Storage
- Uses ESP-IDF `nvs_flash` API (not Arduino Preferences)
- Stores: P1, T, P2, S, autoMode, brightness, sound, weld counters, presets, theme, BLE name
- Auto-save on parameter change (debounced 2s to prevent flash wear)
- Factory reset restores all default presets

---

## Tasks

### Phase A: Display + UI + Audio (testable with board only, no welding hardware)

- [x] **Task 1: PlatformIO project scaffolding** → ✅ Done: 15 files, platformio.ini, sdkconfig.defaults, partitions.csv.

- [x] **Task 2: Display init (LovyanGFX)** → ✅ Done: `display.cpp` with custom LGFX class (QSPI bus, backlight PWM, Touch I2C).

- [x] **Task 3: LVGL 9.x integration** → ✅ Done: `lv_conf.h`, PSRAM draw buffers, flush callback, touch input driver, mutex for thread safety.

- [x] **Task 4: I2S audio** → ✅ Done: `audio.c` with sine wave tone generator, I2S standard driver, command queue, all sound functions.

- [x] **Task 5: Main dashboard UI** → ✅ Done: `ui.c` with status bar, 3 parameter cards (P1/T/P2), S value card, voltage bar, chart (60 points), weld counter, status indicator, settings gear.

- [x] **Task 6: Settings screen + dark/light mode** → ✅ Done: Settings with preset dropdown, brightness slider, sound toggle, theme toggle, version info.

- [x] **Task 7: NVS settings persistence** → ✅ Done: `settings.c` with full NVS read/write, debounced auto-save, factory reset, preset save/load, weld counter persistence.

### Phase B: Welding Logic (requires hardware connected)

- [x] **Task 8: Core welding logic** → ✅ Done: `welding.c` with full state machine (9 states), dual-pulse firing via `ets_delay_us`, charger disconnect, protection monitoring, contact detection, ADC calibration.

- [ ] **Task 9: ADC calibration + test mode** → 🔧 ADC calibration infrastructure in place (`adc_cal_voltage/protection` factors in settings). Calibration wizard UI screen to be added during hardware testing.

- [x] **Task 10: Bluetooth serial** → ✅ Done: `ble_serial.c` with NimBLE GATT service, 3 characteristics (params R/W, status R/notify, commands W), text protocol.

### Phase C: Integration & Polish

- [ ] **Task 11: Full integration test** → ⏳ Requires hardware: flash firmware, connect to welding hardware, verify full cycle.

- [ ] **Task 12: Polish & optimization** → ⏳ Requires hardware testing: tune timings, optimize ADC, add energy calculator.

---

## Done When

- [ ] PlatformIO project compiles with ESP-IDF 5.x + LVGL 9.x + LovyanGFX
- [ ] ESP32-S3 boots and shows full dashboard UI on the 480×320 touchscreen
- [ ] Dark mode and Light mode themes switchable in settings
- [ ] P1/T/P2/S parameters adjustable via touch +/- buttons (0.5ms resolution)
- [ ] MAN mode fires weld pulse ONLY via physical START button (not touchscreen)
- [ ] AUTO mode detects electrode contact and fires after S delay
- [ ] Charger disconnects during weld pulse and reconnects after
- [ ] Live voltage graph and color-coded voltage bar update in real-time (0–5.7V)
- [ ] Weld counter tracks session and total welds
- [ ] 10 preset profiles (7 factory + 3 custom) can be saved/loaded
- [ ] All settings persist across power cycles (NVS)
- [ ] Protection systems work: low supercap voltage (4.0V warn, 3.0V block), gate drive rail out-of-range
- [ ] I2S speaker provides pleasant audio feedback (tones, melodies)
- [ ] BLE serial allows phone to read voltage, change parameters, view weld log
- [ ] ADC calibration wizard matches multimeter readings within ±0.1V

---

## Notes

### ⚠️ Critical Safety Considerations
1. **Physical START button ONLY for MAN mode** — No on-screen weld button. 2000A is not something to trigger accidentally via touch.
2. **CHARGER_EN (IO16) must default LOW on boot** — Charger enabled by default until code explicitly takes control.
3. **OUTPUT_PIN (IO46) must default LOW on boot** — `gpio_set_level(OUTPUT_PIN, 0);` in first lines of `app_main()`.
4. **Gate drive rail must be verified** before any weld is allowed — `checkProtectionVoltage()` runs continuously.
5. **BLE weld trigger requires safety confirmation** — phone command alone cannot fire weld without physical button held.

### 📚 Framework & Library Versions
- **Framework**: PlatformIO + ESP-IDF 5.x (not Arduino)
- **LovyanGFX**: Latest (v1.x) — added as ESP-IDF component
- **LVGL**: v9.x — latest API (`lv_display_*`, `lv_indev_*`)
- **NVS**: ESP-IDF `nvs_flash` API (not Arduino Preferences)
- **I2S**: ESP-IDF `driver/i2s_std.h` (new I2S driver, not legacy)
- **BLE**: ESP-IDF NimBLE stack
- **Board**: ESP32-S3 (N16R8) — PSRAM: OPI, Flash: QIO, Flash Size: 16MB

### 🔌 AXS15231B Display Specifics
- This display uses QSPI (not standard SPI) — needs correct LovyanGFX bus config
- LCD CS pin = **GPIO45** (verified), TE = **GPIO38**
- Touch controller is also AXS15231B (same chip handles display + touch)
- I2C address: 0x3B, Touch RST and INT are **NC** (not connected on this board)
- Some users report needing full-refresh mode with PSRAM buffer for best LVGL compatibility
- Hardware rotation may not be supported — use software rotation if needed

### 🔊 I2S Audio (replaces buzzer)
- Board has a **built-in I2S audio amplifier** (chip U4 on PCB)
- I2S pins: LRCLK=GPIO2, BCLK=GPIO42, DATA=GPIO41
- CTRL connected to VBAT — amp powers on when battery/power is connected
- Speaker connects to **P6** connector (-SP, -VAT)
- Use ESP32-S3 I2S peripheral to generate sine wave tones at various frequencies
- Sound library: use `driver/i2s.h` (ESP-IDF) or Arduino `I2S` library
- **Sound types:**
  - `playBeep()` — 880Hz, 50ms (parameter change confirmation)
  - `playWeldFire()` — 1200Hz, 30ms (pulse fired)
  - `playWeldReady()` — 660Hz→880Hz ascending (caps fully charged)
  - `playError()` — 440Hz→220Hz descending (protection alert)
  - `playStartup()` — C5→E5→G5 arpeggio (boot melody)
  - `playContactDetected()` — 1000Hz, 20ms (AUTO mode contact sense)

### 🔋 Power Input
- ESP32 powered via **P1 connector** (+5VIN pin) from the 3A buck module
- Do NOT use BAT/P5 for 13V — BAT is for 3.7V LiPo only
- USB-C used for programming only during development

### 📐 Voltage Divider Wiring
Original code used 5V Arduino ADC. ESP32-S3 is 3.3V. ALL analog inputs MUST use voltage dividers:
- **Supercap (0–5.7V)**: 10kΩ + 15kΩ divider → 0–2.28V at ADC
- **Protection rail (0–13.5V)**: 47kΩ + 15kΩ divider → 0–3.26V at ADC
- **Contact pin**: 10kΩ pull-up to 3.3V + 100kΩ isolation resistor

### � Supercap Bank Specifications
- **Configuration:** 2S2P (2 series × 2 parallel)
- **Individual cap:** 3.0V, 3000F
- **Bank voltage range:** 0–6.0V (2×3.0V)
- **Operating max:** 5.7V (derated for longevity)
- **Bank capacitance:** 3000F (series halves, parallel doubles → 3000F)
- **Energy at 5.7V:** E = ½CV² = ½ × 3000 × 5.7² = **48,735 Joules** ⚡
- **Estimated peak current:** ~2000A (depends on electrode resistance)
- **Charge time (10A charger):** Q = CV = 3000 × 5.7 = 17,100C → 17,100/10 ≈ **28.5 minutes** (0→5.7V)

### 🔄 NVS Storage Keys
| NVS Key | Type | Default | Notes |
|---|---|---|---|
| `p1` | float | 5.0 | Pulse 1 duration (ms) |
| `t` | float | 8.0 | Pause duration (ms) |
| `p2` | float | 8.0 | Pulse 2 duration (ms, 0=OFF) |
| `autoMode` | bool | false | AUTO/MAN mode |
| `sValue` | float | 0.5 | AUTO mode contact delay (s) |
| `brightness` | uint8_t | 80 | Display brightness (0–100%) |
| `soundOn` | bool | true | Audio enable/disable |
| `theme` | uint8_t | 0 | 0=dark, 1=light |
| `sessionWelds` | uint32_t | 0 | Session weld counter |
| `totalWelds` | uint32_t | 0 | Lifetime weld counter |
| `activePreset` | uint8_t | 1 | Currently selected preset index |
| `preset_0`..`preset_9` | blob | (factory) | 10 preset profiles (weld_preset_t) |
| `adc_cal_v` | float | 1.0 | Voltage ADC calibration factor |
| `adc_cal_p` | float | 1.0 | Protection ADC calibration factor |
| `bleName` | string | "MyWeld" | BLE device name |

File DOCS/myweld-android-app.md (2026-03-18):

# MyWeld Android Companion App — Project Plan

## Goal

Build a **native Kotlin Android companion app** for the MyWeld ESP32 spot welder that communicates via **BLE (Bluetooth Low Energy)** using a **structured binary protocol**. The app provides full control and monitoring: live voltage, parameter adjustment, preset management, weld counter, and multi-device support — all wrapped in a **premium dark/light theme** with metallic accents and glowing visual elements.

---

## Project Type

**MOBILE** — Native Kotlin + Jetpack Compose (Android only)

---

## Decisions (From Brainstorm)

| Decision | Choice | Rationale |
|---|---|---|
| **Feature Scope** | Full Control | Mirror all touchscreen features remotely |
| **BLE Protocol** | Structured binary (Option C) | Robust, extensible, proper error handling — replaces fragile text parsing |
| **Min API** | 26 (Android 8.0+) | ~95% device coverage |
| **UI Style** | Custom Dark Premium + Light mode | Metallic accents, glowing voltage bars, spark animations |
| **Background** | Foreground only | No background service needed for now |
| **Architecture** | Jetpack Compose + MVVM + Koin + Nordic BLE Library | Modern, maintainable, proven BLE handling |
| **Multi-device** | Yes | Scan, connect, save multiple MyWeld devices |

---

## Success Criteria

- [ ] App discovers and connects to MyWeld ESP32 devices via BLE
- [ ] Live supercap voltage, protection voltage, weld state shown in real-time (≤500ms latency)
- [ ] P1/T/P2/S values adjustable from the app with instant feedback
- [ ] AUTO/MAN mode switchable
- [ ] 10 presets loadable and savable
- [ ] Weld counter visible (session + total)
- [ ] Live voltage chart (at least 30 data points rolling)
- [ ] Multi-device: scan, select, remember paired devices
- [ ] Dark mode (default) + Light mode toggle
- [ ] Professional UI with safe area respect (status bar, navigation bar)
- [ ] Works on Android 8.0+ (API 26+)
- [ ] BLE protocol uses structured binary format (both firmware + app updated)

---

## Tech Stack

| Layer | Technology | Rationale |
|---|---|---|
| **Language** | Kotlin 2.0+ | Native Android, modern syntax |
| **UI** | Jetpack Compose + Material 3 | Declarative, custom theming, no XML |
| **Architecture** | MVVM + Repository pattern | Clean separation, testable |
| **DI** | Koin 4.x | Lightweight, no annotation processing |
| **BLE** | Nordic Android BLE Library 2.x | Handles Android BLE quirks (bonding, reconnect, MTU negotiation) |
| **Navigation** | Compose Navigation | Single activity, type-safe routes |
| **State** | StateFlow + ViewModel | Lifecycle-aware, simple |
| **Local Storage** | DataStore (Preferences) | Save paired devices, app preferences |
| **Charts** | Vico (Compose-native charting) | Smooth, animated voltage graph |
| **Build** | Gradle Kotlin DSL + Version Catalogs | Modern, maintainable |
| **Min SDK** | 26 (Android 8.0) | Wide coverage, modern BLE APIs |
| **Target SDK** | 35 (Android 15) | Edge-to-edge, latest APIs |

---

## BLE Protocol V2 — Structured Binary Design

### Why Binary Over Text?

| Aspect | Old (Text) | New (Binary) |
|---|---|---|
| **Parsing** | `sscanf("P1=%f")` — fragile | Fixed offsets — robust |
| **Size** | ~80 bytes per status | ~46 bytes — faster BLE |
| **Error handling** | None (fire-and-forget) | ACK/NAK with error codes |
| **Extensibility** | Add new field = break parser | Version + type field = safe extension |
| **Endianness** | N/A | Little-endian (ESP32 native) |

### Protocol Packet Structure

```
┌──────┬──────┬──────┬──────────────────────────┬──────┐
│ SYNC │ TYPE │  LEN │        PAYLOAD           │  CRC │
│ 0xAA │ 1B   │ 1B   │   0–240 bytes            │  1B  │
└──────┴──────┴──────┴──────────────────────────┴──────┘
```

| Field | Size | Description |
|---|---|---|
| SYNC | 1 byte | Always `0xAA` — packet start marker |
| TYPE | 1 byte | Message type (see table below) |
| LEN | 1 byte | Payload length (0–240) |
| PAYLOAD | 0–240 bytes | Type-specific data |
| CRC | 1 byte | XOR checksum of TYPE + LEN + PAYLOAD |

### Message Types

| Type | Hex | Direction | Payload | Description |
|---|-----|---|---|---|
| STATUS | `0x01` | ESP→App (notify) | 46 bytes | Periodic status update |
| PARAMS_READ | `0x02` | App→ESP (read) | 0 | Request current parameters |
| PARAMS_RESPONSE | `0x03` | ESP→App | 28 bytes | Current parameter values |
| PARAMS_WRITE | `0x04` | App→ESP (write) | 28 bytes | Set new parameters |
| CMD | `0x05` | App→ESP (write) | varies | Commands (load preset, reset, etc.) |
| ACK | `0x06` | ESP→App (notify) | 2 bytes | Success: [original_type, 0x00] |
| NAK | `0x07` | ESP→App (notify) | 3 bytes | Error: [original_type, error_code, 0x00] |
| VERSION | `0x08` | App→ESP (read) | 0 | Request firmware version |
| VERSION_RESPONSE | `0x09` | ESP→App | 12 bytes | Version + build date |
| PRESET_LIST | `0x0A` | App→ESP (read) | 0 | Request all preset names |
| PRESET_LIST_RESPONSE | `0x0B` | ESP→App (notify) | varies | Preset names (chunked if needed) |
| WELD_LOG_ENTRY | `0x0C` | ESP→App (notify) | 12 bytes | Weld log event (timestamp, energy, voltage) |

### STATUS Payload (0x01) — 46 bytes, sent every ~500ms

```c
typedef struct __attribute__((packed)) {
    uint16_t supercap_mv;       // Supercap voltage in millivolts (0–12000)
    uint16_t protection_mv;     // Protection rail in millivolts (0–18000)
    uint8_t  state;             // Weld state enum (IDLE=0, ARMED=1, PRE_FIRE=2, FIRING_P1=3, ...)
    uint8_t  charge_percent;    // 0–100%
    uint8_t  auto_mode;         // 0=MAN, 1=AUTO
    uint8_t  active_preset;     // 0–19 (0xFF = user-defined)
    uint32_t session_welds;     // Session weld counter
    uint32_t total_welds;       // Lifetime weld counter
    uint8_t  ble_connected;     // 1 if BLE connected
    uint8_t  sound_on;          // 0=mute, 1=on
    uint8_t  theme;             // 0=dark, 1=light
    uint8_t  error_code;        // 0=none, see error enum
    uint16_t p1_x10;            // P1 in 0.1ms units (e.g., 50 = 5.0ms)
    uint16_t t_x10;             // T in 0.1ms units
    uint16_t p2_x10;            // P2 in 0.1ms units
    uint16_t p3_x10;            // P3 in 0.1ms units (0 = disabled)
    uint16_t p4_x10;            // P4 in 0.1ms units (0 = disabled)
    uint16_t s_x10;             // S in 0.1s units (e.g., 5 = 0.5s)
    uint8_t  fw_major;          // Firmware major version
    uint8_t  fw_minor;          // Firmware minor version
    uint8_t  volume;            // Master volume 0–100%
    uint8_t  auth_lockout_sec;  // Remaining lockout seconds (0 = no lockout)
    uint16_t raw_supercap_mv;   // Uncalibrated supercap voltage (mV)
    uint16_t raw_protection_mv; // Uncalibrated protection voltage (mV)
    uint16_t cal_factor_v_x1000; // Supercap cal factor × 1000
    uint16_t cal_factor_p_x1000; // Protection cal factor × 1000
    uint16_t max_supercap_mv;   // Configured max supercap voltage (mV)
} ble_status_packet_t;          // Total: 46 bytes
```

### PARAMS_WRITE Payload (0x04) — 28 bytes

```c
typedef struct __attribute__((packed)) {
    uint16_t p1_x10;            // P1 in 0.1ms units
    uint16_t t_x10;             // T in 0.1ms units
    uint16_t p2_x10;            // P2 in 0.1ms units
    uint16_t s_x10;             // S in 0.1s units
    uint8_t  auto_mode;         // 0=MAN, 1=AUTO
    uint8_t  sound_on;          // 0=mute, 1=on
    uint8_t  brightness;        // 0–100%
    uint8_t  theme;             // 0=dark, 1=light
    char     ble_name[16];      // Device BLE name (null-terminated)
} ble_params_packet_t;          // Total: 28 bytes
```

### CMD Payload (0x05)

| Sub-command | Byte 0 | Extra | Description |
|---|---|---|---|
| LOAD_PRESET | `0x01` | `[preset_index]` | Load preset 0–9 |
| SAVE_PRESET | `0x02` | `[index, name[20], p1, t, p2, s, mode]` | Save current params as preset |
| FACTORY_RESET | `0x03` | none | Reset all settings to factory |
| RESET_WELD_COUNTER | `0x04` | `[0=session, 1=total, 2=both]` | Reset weld counters |
| CALIBRATE_ADC | `0x05` | `[channel, reference_mv_u16]` | ADC calibration |

### Error Codes (NAK payload byte 1)

| Code | Meaning |
|---|---|
| `0x01` | Invalid parameter range |
| `0x02` | Invalid preset index |
| `0x03` | NVS write failure |
| `0x04` | Busy (welding in progress) |
| `0x05` | Unknown command |

### BLE GATT Service (Updated UUIDs)

| Characteristic | UUID | Properties | Description |
|---|---|---|---|
| **TX (Status)** | `12360000-...` | READ, NOTIFY | ESP32→App: status packets, ACK/NAK |
| **RX (Command)** | `12370000-...` | WRITE, WRITE_NO_RESPONSE | App→ESP32: params write, commands |
| **Params** | `12350000-...` | READ | One-shot read of current params |

---

## App File Structure

```
MyWeld-Android/
├── app/
│   ├── build.gradle.kts
│   └── src/main/
│       ├── AndroidManifest.xml
│       ├── java/com/myweld/app/
│       │   ├── MyWeldApp.kt                    # Application class + Koin init
│       │   ├── MainActivity.kt                 # Single activity, edge-to-edge
│       │   │
│       │   ├── navigation/
│       │   │   └── NavGraph.kt                 # Compose Navigation routes
│       │   │
│       │   ├── ui/
│       │   │   ├── theme/
│       │   │   │   ├── Theme.kt                # Dark/Light premium theme
│       │   │   │   ├── Color.kt                # Color palette (metallic, glow)
│       │   │   │   ├── Type.kt                 # Typography (Roboto/custom)
│       │   │   │   └── Shape.kt                # Shapes, corner radii
│       │   │   │
│       │   │   ├── screens/
│       │   │   │   ├── ScanScreen.kt           # BLE device scanner + picker
│       │   │   │   ├── DashboardScreen.kt      # Main control dashboard
│       │   │   │   ├── PresetsScreen.kt        # Preset manager (10 slots)
│       │   │   │   ├── SettingsScreen.kt       # App + device settings
│       │   │   │   └── AboutScreen.kt          # Version info, credits
│       │   │   │
│       │   │   └── components/
│       │   │       ├── VoltageBar.kt           # Glowing voltage bar with gradient
│       │   │       ├── VoltageChart.kt         # Live rolling voltage graph
│       │   │       ├── ParamCard.kt            # P1/T/P2/S parameter card with +/-
│       │   │       ├── StatusIndicator.kt      # IDLE/READY/CHARGING/FIRING/ERROR
│       │   │       ├── WeldCounter.kt          # Session + total counter display
│       │   │       ├── ConnectionBadge.kt      # BLE connection status badge
│       │   │       ├── PresetCard.kt           # Individual preset card
│       │   │       ├── DeviceCard.kt           # BLE device in scan list
│       │   │       └── GlowButton.kt           # Custom glowing button component
│       │   │
│       │   ├── viewmodel/
│       │   │   ├── ScanViewModel.kt            # BLE scan state
│       │   │   ├── DashboardViewModel.kt       # Dashboard state + BLE data
│       │   │   ├── PresetsViewModel.kt         # Preset management
│       │   │   └── SettingsViewModel.kt        # Settings state
│       │   │
│       │   ├── data/
│       │   │   ├── model/
│       │   │   │   ├── WelderStatus.kt         # Domain model for status
│       │   │   │   ├── WeldParams.kt           # Domain model for parameters
│       │   │   │   ├── WeldPreset.kt           # Domain model for presets
│       │   │   │   ├── WeldState.kt            # Enum: IDLE, READY, etc.
│       │   │   │   └── SavedDevice.kt          # Persisted BLE device info
│       │   │   │
│       │   │   ├── ble/
│       │   │   │   ├── MyWeldBleManager.kt     # Nordic BLE Library manager
│       │   │   │   ├── BleProtocol.kt          # Binary protocol encode/decode
│       │   │   │   ├── BlePacket.kt            # Packet structure definitions
│       │   │   │   ├── BleUuids.kt             # Service/characteristic UUIDs
│       │   │   │   └── BleConnectionState.kt   # Connection state sealed class
│       │   │   │
│       │   │   └── repository/
│       │   │       ├── WelderRepository.kt     # Interface: welder data access
│       │   │       ├── WelderRepositoryImpl.kt # Implementation via BLE
│       │   │       └── DeviceRepository.kt     # Saved devices (DataStore)
│       │   │
│       │   └── di/
│       │       └── AppModule.kt                # Koin dependency definitions
│       │
│       └── res/
│           ├── values/
│           │   ├── strings.xml
│           │   └── themes.xml                  # Edge-to-edge setup
│           ├── drawable/                        # App icon, vectors
│           └── mipmap/                          # Launcher icons
│
├── build.gradle.kts                            # Root build config
├── settings.gradle.kts                         # Module settings
└── gradle/
    └── libs.versions.toml                      # Version catalog
```

---

## Task Breakdown

### Phase A: Project Foundation (No BLE yet)

#### Task A1: Create Android Project
- **Agent:** `mobile-developer`
- **Skills:** `clean-code`, `mobile-design`
- **Priority:** P0 (blocker for everything)
- **Dependencies:** None
- **INPUT:** Empty directory
- **OUTPUT:** Compilable Kotlin + Compose project with:
  - `build.gradle.kts` with all dependencies (Compose, Koin, Nordic BLE, Vico, DataStore)
  - `libs.versions.toml` version catalog
  - `AndroidManifest.xml` with BLE permissions (`BLUETOOTH_CONNECT`, `BLUETOOTH_SCAN`, `ACCESS_FINE_LOCATION` for API <31)
  - `MainActivity.kt` with edge-to-edge setup (`WindowCompat.setDecorFitsSystemWindows(window, false)`)
  - `MyWeldApp.kt` application class with Koin initialization
- **VERIFY:** `./gradlew assembleDebug` succeeds

#### Task A2: Premium Theme System
- **Agent:** `mobile-developer`
- **Skills:** `mobile-design`, `frontend-design`
- **Priority:** P0 (affects all UI)
- **Dependencies:** A1
- **INPUT:** Theme design requirements (dark premium + light mode)
- **OUTPUT:**
  - `Color.kt` — Dual palette: dark (charcoal #1A1A2E, deep navy #16213E, metallic silver #C0C0C0, neon cyan #00D4FF, ember orange #FF6B35, voltage green #39FF14) and light mode equivalents
  - `Theme.kt` — Custom M3 `MaterialTheme` with custom `ColorScheme` for both modes
  - `Type.kt` — Typography scale using Roboto + monospace for values
  - `Shape.kt` — Rounded corners with subtle metallic border effects
- **VERIFY:** Toggle dark/light, all colors are correct and readable, no purple/violet

#### Task A3: Navigation Structure
- **Agent:** `mobile-developer`
- **Skills:** `clean-code`
- **Priority:** P0
- **Dependencies:** A1, A2
- **INPUT:** Screen list: Scan → Dashboard → Presets, Settings, About
- **OUTPUT:**
  - `NavGraph.kt` with 5 routes
  - Bottom navigation bar for Dashboard/Presets/Settings (only visible after connection)
  - Scan screen as start destination
- **VERIFY:** Can navigate between all screens, back navigation works, safe areas respected

---

### Phase B: BLE Communication Layer

#### Task B1: BLE Protocol Module (App Side)
- **Agent:** `mobile-developer`
- **Skills:** `clean-code`
- **Priority:** P0 (blocker for all BLE features)
- **Dependencies:** A1
- **INPUT:** Protocol spec from this plan (binary format)
- **OUTPUT:**
  - `BlePacket.kt` — Data classes for all packet types
  - `BleProtocol.kt` — Encoder/decoder: `ByteArray ↔ Kotlin data classes`, CRC calculation
  - `BleUuids.kt` — Service and characteristic UUIDs (matching firmware)
  - `BleConnectionState.kt` — Sealed class: `Disconnected`, `Scanning`, `Connecting`, `Connected`, `Error`
- **VERIFY:** Unit tests: encode STATUS packet → decode → original values match, CRC validates

#### Task B2: BLE Manager (Nordic Library Integration)
- **Agent:** `mobile-developer`
- **Skills:** `clean-code`
- **Priority:** P0
- **Dependencies:** B1
- **INPUT:** Nordic BLE Library API, UUID config
- **OUTPUT:**
  - `MyWeldBleManager.kt` extending `BleManager`:
    - `scan()` — discover MyWeld devices (filter by service UUID)
    - `connect(device)` — connect with MTU negotiation (request 247)
    - `disconnect()`
    - `StatusFlow: StateFlow<WelderStatus>` — parsed status updates
    - `connectionState: StateFlow<BleConnectionState>`
    - `writeParams(params)` — send PARAMS_WRITE
    - `sendCommand(cmd)` — send CMD packets
    - `readParams()` — one-shot params read
    - Handle notifications on TX characteristic → parse → emit to flows
- **VERIFY:** Connect to ESP32 (or mock), receive status notifications, send a param write and get ACK

#### Task B3: Repository Layer
- **Agent:** `mobile-developer`
- **Skills:** `clean-code`
- **Priority:** P1
- **Dependencies:** B2
- **INPUT:** BLE manager, DataStore
- **OUTPUT:**
  - `WelderRepository.kt` — Interface with `statusFlow`, `paramsFlow`, `connect()`, `writeParams()`, `loadPreset()`, etc.
  - `WelderRepositoryImpl.kt` — Delegates to BleManager, handles reconnection logic
  - `DeviceRepository.kt` — Persists paired devices (MAC, name, last seen) via DataStore
- **VERIFY:** Repository correctly exposes BLE data as Kotlin Flows

#### Task B4: Firmware BLE Protocol Update (ESP32 Side)
- **Agent:** `mobile-developer` (embedded context)
- **Skills:** `clean-code`
- **Priority:** P0 (must match app protocol)
- **Dependencies:** None (can be parallel with app tasks)
- **INPUT:** Current `ble_serial.c` + binary protocol spec
- **OUTPUT:**
  - Updated `ble_serial.c`:
    - Replace text protocol with binary packet encoding/decoding
    - Add CRC calculation
    - Add ACK/NAK responses for writes
    - Add VERSION_RESPONSE handler
    - Add PRESET_LIST_RESPONSE handler
    - Status notify sends binary `ble_status_packet_t` every 500ms
  - New `ble_protocol.h` — Shared packet structures and constants
  - Updated `ble_serial.h` — Same public API, different internal format
- **VERIFY:** `pio run` compiles, BLE protocol visible via nRF Connect app (raw bytes match spec)

---

### Phase C: UI Screens

#### Task C1: Scan Screen
- **Agent:** `mobile-developer`
- **Skills:** `mobile-design`
- **Priority:** P1
- **Dependencies:** A2, A3, B2
- **INPUT:** BLE scan results, saved devices
- **OUTPUT:**
  - `ScanScreen.kt`:
    - "Pull to scan" or scan button with animated radar/pulse effect
    - `DeviceCard.kt` for each discovered device (name, signal strength, last seen)
    - Saved devices section (previously connected)
    - Permission request dialog for BLE/Location
    - Connection progress indicator
  - `ScanViewModel.kt` — scan start/stop, device list, connect action
- **VERIFY:** Scan discovers ESP32, tap connects, navigates to Dashboard

#### Task C2: Dashboard Screen (Main)
- **Agent:** `mobile-developer`
- **Skills:** `mobile-design`, `frontend-design`
- **Priority:** P1
- **Dependencies:** A2, A3, B3, C1
- **INPUT:** `WelderStatus` flow from repository
- **OUTPUT:**
  - `DashboardScreen.kt`:
    - **Top:** Connection badge (device name + signal + state) — respects status bar safe area
    - **Voltage section:** `VoltageBar.kt` (gradient green→yellow→red with glow effect, percentage, actual V)
    - **Parameters:** 3× `ParamCard.kt` for P1/T/P2 (big value, +/- buttons, 0.5ms step)
    - **S value card** (only visible in AUTO mode)
    - **Mode toggle:** AUTO/MAN animated switch
    - **Chart:** `VoltageChart.kt` (rolling 30-point line chart using Vico)
    - **Bottom:** `WeldCounter.kt` (session/total) + `StatusIndicator.kt` (IDLE/READY/CHARGING/FIRING/ERROR with color coding)
    - All respects navigation bar safe area
  - `DashboardViewModel.kt` — observes repo flows, dispatches param writes
  - Custom components: `VoltageBar.kt`, `VoltageChart.kt`, `ParamCard.kt`, `StatusIndicator.kt`, `WeldCounter.kt`, `ConnectionBadge.kt`
- **VERIFY:** Live data updates, tap +/- changes values, mode toggle works, chart animates

#### Task C3: Presets Screen
- **Agent:** `mobile-developer`
- **Skills:** `mobile-design`
- **Priority:** P2
- **Dependencies:** A2, A3, B3
- **INPUT:** Preset list from BLE
- **OUTPUT:**
  - `PresetsScreen.kt`:
    - Grid/list of 10 `PresetCard.kt` (name, P1/T/P2 values, active indicator)
    - Tap to load preset (sends CMD to ESP32)
    - Long-press to edit name
    - "Save Current" button — saves current params to selected slot
    - Factory presets have a "lock" icon (can still be overwritten)
  - `PresetsViewModel.kt`
- **VERIFY:** Load preset → dashboard values update, save preset → persists on ESP32

#### Task C4: Settings Screen
- **Agent:** `mobile-developer`
- **Skills:** `mobile-design`
- **Priority:** P2
- **Dependencies:** A2, A3, B3
- **INPUT:** Device + app settings
- **OUTPUT:**
  - `SettingsScreen.kt`:
    - **Device settings** (synced via BLE): BLE device name, sound on/off, display brightness, display theme
    - **App settings** (local): Dark/Light mode toggle, auto-reconnect on/off
    - **Saved devices:** List of remembered devices with forget option
    - **Factory reset** button (with confirmation dialog)
    - **Weld counter reset** (session/total)
    - **About section:** Firmware version (from VERSION response), app version
  - `SettingsViewModel.kt`
- **VERIFY:** Toggle settings → ESP32 responds with ACK, app theme switches instantly

#### Task C5: Custom UI Components Polish
- **Agent:** `mobile-developer`
- **Skills:** `mobile-design`, `frontend-design`
- **Priority:** P2
- **Dependencies:** C2
- **INPUT:** All working screens
- **OUTPUT:**
  - `GlowButton.kt` — Custom button with neon glow/pulse animation
  - `VoltageBar.kt` polish — Canvas-drawn gradient bar with animated glow shader
  - `StatusIndicator.kt` polish — Pulsing dot animation for CHARGING, spark animation for FIRING
  - `ParamCard.kt` polish — Metallic card border, haptic feedback on +/-
  - Dark/Light mode transition animation
  - Connection lost overlay with reconnect animation
- **VERIFY:** Visual polish matches "premium" quality, all animations smooth at 60fps

---

### Phase D: Integration & Testing

#### Task D1: End-to-End Integration Test
- **Agent:** `mobile-developer`
- **Skills:** `testing-patterns`
- **Priority:** P1
- **Dependencies:** B4, C2
- **INPUT:** Flashed ESP32 + Android app
- **OUTPUT:**
  - Connect to real ESP32 via BLE
  - Verify status updates arrive and parse correctly
  - Verify param writes succeed (ACK received)
  - Verify preset load works
  - Verify reconnection after disconnect
  - Test at edge of BLE range
- **VERIFY:** Full cycle works: scan → connect → monitor → adjust → preset → disconnect → reconnect

#### Task D2: Unit Tests
- **Agent:** `mobile-developer`
- **Skills:** `testing-patterns`
- **Priority:** P2
- **Dependencies:** B1, B3
- **INPUT:** Protocol module, repository
- **OUTPUT:**
  - Protocol tests: encode/decode all packet types, CRC validation, edge cases (max values, zero values)
  - ViewModel tests: state transitions, error handling
  - Repository tests: mock BLE manager
- **VERIFY:** `./gradlew test` passes with ≥80% coverage on protocol module

#### Task D3: Error Handling & Edge Cases
- **Agent:** `mobile-developer`
- **Skills:** `clean-code`
- **Priority:** P2
- **Dependencies:** D1
- **INPUT:** Test results from D1
- **OUTPUT:**
  - BLE disconnection handling (show reconnect overlay, auto-retry 3×)
  - Permission denied handling (guide user to settings)
  - BLE off handling (prompt to enable)
  - Timeout handling (NAK not received within 2s → show error)
  - Invalid packet handling (CRC mismatch → log + ignore)
- **VERIFY:** App never crashes on BLE disconnect, always shows meaningful error state

---

### Phase X: Verification

- [ ] `./gradlew assembleDebug` succeeds
- [ ] `./gradlew test` passes
- [ ] App installs on API 26 device/emulator
- [ ] BLE scan finds ESP32 device
- [ ] Full control cycle works (connect → monitor → adjust → disconnect)
- [ ] Dark mode looks premium (no plain colors, has glow/metallic effects)
- [ ] Light mode looks clean and readable
- [ ] Status bar and navigation bar safe areas respected
- [ ] No purple/violet colors anywhere
- [ ] Touch targets ≥ 48dp
- [ ] Back navigation works correctly on all screens
- [ ] `python .agent/skills/mobile-design/scripts/mobile_audit.py` passes

---

## Architecture Diagram

```
┌───────────────────────────────────────────────────────────┐
│                    ANDROID APP                            │
│                                                           │
│  ┌──────────┐  ┌──────────┐  ┌──────────┐  ┌──────────┐ │
│  │  Scan    │  │Dashboard │  │ Presets  │  │ Settings │ │
│  │ Screen   │  │ Screen   │  │ Screen   │  │ Screen   │ │
│  └────┬─────┘  └────┬─────┘  └────┬─────┘  └────┬─────┘ │
│       │              │              │              │       │
│  ┌────▼─────┐  ┌────▼─────┐  ┌────▼─────┐  ┌────▼─────┐ │
│  │  Scan   │  │Dashboard │  │ Presets │  │ Settings │ │
│  │ViewModel│  │ViewModel │  │ViewModel│  │ViewModel │ │
│  └────┬─────┘  └────┬─────┘  └────┬─────┘  └────┬─────┘ │
│       │              │              │              │       │
│       └──────────────┼──────────────┼──────────────┘       │
│                      │              │                      │
│              ┌───────▼──────────────▼────────┐             │
│              │     WelderRepository          │             │
│              │  (Interface + Impl)           │             │
│              └───────────────┬───────────────┘             │
│                              │                             │
│              ┌───────────────▼───────────────┐             │
│              │     MyWeldBleManager          │             │
│              │  (Nordic BLE Library)         │             │
│              └───────────────┬───────────────┘             │
│                              │                             │
│              ┌───────────────▼───────────────┐             │
│              │     BleProtocol               │             │
│              │  (Binary encode/decode)       │             │
│              └───────────────┬───────────────┘             │
│                              │                             │
└──────────────────────────────┼─────────────────────────────┘
                               │ BLE GATT
                               │
┌──────────────────────────────┼─────────────────────────────┐
│              ESP32-S3        │                              │
│              ┌───────────────▼───────────────┐             │
│              │     ble_serial.c              │             │
│              │  (Binary protocol V2)         │             │
│              └───────────────┬───────────────┘             │
│                              │                             │
│              ┌───────────────▼───────────────┐             │
│              │  welding.c / settings.c / ui.c│             │
│              └───────────────────────────────┘             │
└────────────────────────────────────────────────────────────┘
```

---

## Risk Assessment

| Risk | Impact | Mitigation |
|---|---|---|
| BLE Android quirks (Samsung, Xiaomi) | High | Nordic BLE Library handles most; test on 2+ devices |
| Binary protocol sync issues | Medium | CRC + SYNC byte + timeout/retry logic |
| BLE MTU too small for preset list | Low | Chunked PRESET_LIST_RESPONSE or request one-by-one |
| Compose performance on old devices | Medium | Profile on API 26 device, use `remember` aggressively |
| Firmware binary protocol change | High | Version field in STATUS allows backward compat |

---

## Notes

- **Safety:** The app CANNOT trigger a weld. The physical START button is the only weld trigger. The app can only set parameters and monitor — this is enforced at the firmware level.
- **BLE Name:** Default is "MyWeld" — the app filters for devices advertising this service UUID, not by name, so custom names work.
- **Weld Log:** For V1, weld log is limited to the session/total counters. Full timestamped weld history would require SD card logging on the ESP32 (future feature).
- **Firmware backward compat:** If the app connects and receives a text-format response instead of binary, it should show "Firmware update required" message. Check first byte — if it's ASCII (> 0x20) instead of 0xAA, it's legacy text protocol.

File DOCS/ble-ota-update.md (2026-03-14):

# BLE OTA Firmware Update

## Goal
Enable users to update ESP32 firmware wirelessly via BLE from the Android app. User picks a `.bin` file locally OR the app auto-detects new GitHub releases. PIN authentication required before flashing. Progress displayed on both phone and device. Rollback on bad firmware.

---

## Architecture Overview

```
Android App                          ESP32 Firmware
──────────────                       ──────────────
┌──────────────┐                     ┌────────────────┐
│ FirmwareVM   │ ── OTA_BEGIN ──►    │ ota.c          │
│              │ ── OTA_DATA  ──►    │  esp_ota_*()   │
│ OtaService   │ ◄── OTA_ACK ──     │  partition mgr │
│              │ ── OTA_END   ──►    │  rollback      │
│ GitHub API   │ ◄── OTA_DONE ──     │                │
└──────────────┘                     └────────────────┘

BLE Protocol Extension (0x10–0x15):
  OTA_BEGIN  (0x10) App→ESP : [total_size_u32][sha256_32B][fw_major][fw_minor][fw_patch]
  OTA_DATA   (0x11) App→ESP : [seq_u16][chunk_data_up_to_240B]
  OTA_END    (0x12) App→ESP : (no payload — signals transfer complete)
  OTA_ACK    (0x13) ESP→App : [status_u8][progress_u8][seq_u16]
  OTA_ABORT  (0x14) Either  : [reason_u8]
  OTA_RESULT (0x15) ESP→App : [result_u8] (0=OK, 1=CRC_FAIL, 2=FLASH_ERR, 3=ROLLBACK)
```

## Key Design Decisions

1. **Partition Table**: Dual OTA slots (`ota_0`, `ota_1`) + `otadata`, 3MB per slot (fw is ~1.14MB)
2. **Chunk Size**: 240 bytes per `OTA_DATA` packet (fits in 255-byte protocol LEN limit)
3. **Flow Control**: ESP32 sends `OTA_ACK` per chunk; app waits before next chunk
4. **Welding Lockout**: Welding disabled during OTA (safety critical)
5. **ESP32 Display**: Shows OTA progress bar + percentage via LVGL overlay
6. **Rollback**: `esp_ota_mark_app_valid_cancel_rollback()` called after stable boot

---

## Tasks

### Phase 1: ESP32 Partition & OTA Foundation

- [x] **Task 1**: Update `partitions.csv` for dual OTA layout
  ```
  # Name,   Type, SubType, Offset,   Size
  nvs,      data, nvs,     0x9000,   0x6000,
  otadata,  data, ota,     0xF000,   0x2000,
  phy_init, data, phy,     0x11000,  0x1000,
  ota_0,    app,  ota_0,   0x20000,  0x300000,
  ota_1,    app,  ota_1,   0x320000, 0x300000,
  storage,  data, spiffs,  0x620000, 0x9E0000,
  ```
  → Verify: `idf.py build` succeeds, flash size < 3MB

- [x] **Task 2**: Add OTA protocol definitions to `ble_protocol.h`
  - New message types `0x10–0x15`
  - `ble_ota_begin_t` struct (39 bytes: u32 total_size + 32B SHA256 + 3B version)
  - `ble_ota_data_t` struct (2B seq + up to 240B data)
  - `ble_ota_ack_t` struct (1B status + 1B progress + 2B seq)
  - `ble_ota_result_t` struct (1B result)
  - OTA error codes
  → Verify: Compiles with no warnings

- [x] **Task 3**: Create `ota.c` / `ota.h` — ESP32 OTA engine
  - `ota_begin(total_size, sha256_expected)` → open inactive OTA partition, erase
  - `ota_write_chunk(seq, data, len)` → `esp_ota_write()`, track progress
  - `ota_finish()` → validate SHA256, `esp_ota_set_boot_partition()`, reboot
  - `ota_abort()` → cleanup, release partition handle
  - `ota_get_progress()` → returns 0–100
  - Internal state machine: `IDLE → RECEIVING → VALIDATING → REBOOTING`
  → Verify: Functions compile, state machine transitions correct

- [x] **Task 4**: Wire OTA into `ble_serial.c`
  - Add OTA characteristic (UUID `0x1238`) with WRITE+NOTIFY
  - Handle `OTA_BEGIN`, `OTA_DATA`, `OTA_END` in new `ota_access_cb()`
  - Check PIN auth before accepting `OTA_BEGIN` (reuse `s_authenticated` flag)
  - Disable status notify during OTA (to save bandwidth)
  - Lock out welding during OTA via `welding_set_ota_lock(true)`
  → Verify: OTA characteristic appears in GATT service scan

- [x] **Task 5**: Add rollback validation in `main.c`
  - On boot: check `esp_ota_check_rollback_is_possible()`
  - After successful init (display + BLE + welding all OK): `esp_ota_mark_app_valid_cancel_rollback()`
  - If boot fails 3 times → auto-rollback to previous firmware
  → Verify: Boot log shows "App marked valid" or rollback message

- [x] **Task 6**: OTA progress UI overlay on ESP32 display
  - Add `ui_show_ota_progress(uint8_t percent)` and `ui_hide_ota_progress()`
  - Full-screen overlay: "Firmware Update" title + progress bar + percentage
  - "DO NOT POWER OFF" warning text
  - Called from `ota.c` on each chunk ACK
  → Verify: Calling `ui_show_ota_progress(50)` displays 50% progress

### Phase 2: Android Protocol & OTA Service

- [x] **Task 7**: Add OTA protocol to `BleProtocol.kt`
  - `encodeOtaBegin(totalSize, sha256, major, minor, patch)` → packet
  - `encodeOtaData(seq, chunkData)` → packet
  - `encodeOtaEnd()` → packet
  - `encodeOtaAbort(reason)` → packet
  - `decodeOtaAck(payload)` → `OtaAckResult(status, progress, seq)`
  - `decodeOtaResult(payload)` → `OtaResult(success, errorCode)`
  → Verify: Unit tests for encode/decode

- [x] **Task 8**: Add OTA UUID + handlers to `BleUuids.kt` & `MyWeldBleManager.kt`
  - New UUID `CHAR_OTA = 0x1238`
  - Discover + subscribe to OTA characteristic
  - `sendOtaPacket()` method with write-with-response for reliability
  - Handle `OTA_ACK` and `OTA_RESULT` notifications
  - Expose `otaProgress: SharedFlow<OtaProgress>` and `otaResult: SharedFlow<OtaResult>`
  → Verify: OTA characteristic discovered on connect

- [x] **Task 9**: Create `OtaService.kt` — chunked transfer engine
  - Input: `InputStream` (from file picker or download) + file size
  - Compute SHA256 of entire binary before starting
  - Send `OTA_BEGIN` → wait for ACK
  - Loop: read 240B chunk → `OTA_DATA(seq)` → wait for ACK → update progress
  - Send `OTA_END` → wait for `OTA_RESULT`
  - Timeout handling: 5s per chunk, 3 retries before abort
  - Cancel support (user can cancel mid-transfer)
  - Emit progress events for UI
  → Verify: Can send a test binary of ~1MB, progress flows correctly

- [x] **Task 10**: Create `FirmwareViewModel.kt`
  - State: `currentVersion`, `availableVersion`, `otaState` (Idle/Checking/Downloading/Uploading/Done/Error)
  - `checkGitHubReleases()` — fetch latest release from GitHub API, compare versions
  - `startOtaFromFile(uri: Uri)` — file picker flow
  - `startOtaFromGitHub(releaseUrl)` — download + flash flow
  - Require PIN auth before starting (verify `isAuthenticated` from BleManager)
  → Verify: ViewModel states transition correctly

### Phase 3: Android UI — Firmware Update Screen

- [x] **Task 11**: Create `FirmwareUpdateScreen.kt`
  - **Top section**: Current firmware version (from device status)
  - **Update available card**: Shows new version + changelog (from GitHub)
  - **Manual update button**: Opens file picker (`.bin` files)
  - **Auto-update button**: Downloads latest from GitHub
  - **Progress section** (during OTA): Circular progress + percentage + "Do not disconnect" warning
  - **Result section**: Success (with reboot countdown) or Error (with retry option)
  - PIN dialog before starting OTA
  → Verify: Screen renders, file picker opens, progress animates

- [x] **Task 12**: Add navigation route + menu entry
  - Add "Firmware Update" to navigation graph
  - Add entry in Settings screen or bottom nav
  - Badge indicator when update available (optional)
  → Verify: Can navigate to Firmware Update screen from Settings

### Phase 4: GitHub Release Integration

- [x] **Task 13**: Create `GitHubReleaseChecker.kt`
  - Uses GitHub REST API: `GET /repos/{owner}/{repo}/releases/latest`
  - Parse version tag (e.g., `v1.0.1`) → compare with device version
  - Download `.bin` asset URL
  - Cache check result (don't spam API — check max once per app launch)
  - No API key required for public repos
  → Verify: Fetches release info from test GitHub repo

### Phase 5: Verification

- [x] **Task 14**: End-to-end test
  - Build firmware v1.0.1 with a small change (e.g., version string)
  - Flash v1.0.0 normally via USB
  - Use Android app to OTA-flash v1.0.1 via file picker
  - Verify: Device reboots, shows v1.0.1, rollback protection active
  - Verify: Progress shown on both phone and device display
  - Test abort mid-transfer → device stays on old firmware
  - Test rollback: flash bad binary → device auto-reverts

---

## Done When
- [ ] ESP32 boots from OTA partition with rollback protection
- [ ] Android app can pick `.bin` file and flash over BLE with progress
- [ ] Android app can check GitHub releases and auto-download + flash
- [ ] PIN required before OTA starts
- [ ] Progress shown on both Android app and ESP32 display
- [ ] Welding locked out during OTA
- [ ] Abort and rollback work correctly

## Notes
- **Chunk math**: 1.14MB / 240B = ~4,979 chunks. At ~30KB/s = ~38 seconds. Acceptable.
- **MTU negotiation**: NordicSemi BleManager handles MTU automatically; request 517 for max throughput.
- **GitHub repo**: User needs to provide `{owner}/{repo}` — can be hardcoded or configurable in app settings.
- **sdkconfig**: May need `CONFIG_BOOTLOADER_APP_ROLLBACK_ENABLE=y` and `CONFIG_BOOTLOADER_OTA_DATA_ERASE=y`.
- **Current protocol LEN limit**: LEN is `uint8_t` (max 255). OTA_DATA payload = 2B seq + 240B data = 242B ✅ fits.

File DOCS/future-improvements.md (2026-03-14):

# MyWeld — Future Improvements & Feature Ideas

> **Created:** 2026-02-26
> **Status:** Brainstorm — none of these are committed yet.
> **Context:** The project already has a complete ESP32 firmware (LVGL dashboard, I2S audio, NVS presets, BLE binary protocol, OTA updates) and a full Android companion app (Jetpack Compose, Nordic BLE, binary protocol, OTA from GitHub).

---

## 🔥 Tier 1: High-Impact Features

### 1. 📊 Weld Quality Scoring & History

**Problem:** Currently we track weld count but not weld quality.

**Idea:**
- Measure **voltage drop during pulse** (ΔV = V_before − V_after) — this correlates with energy delivered
- Calculate **energy per weld**: `E = ½C(V₁² − V₂²)` (from supercap voltage delta, C ≈ 3000F)
- Score each weld (Green / Yellow / Red) based on expected ΔV for the selected material
- **Log timestamped history to SD card** (GPIO 10-13 already wired to TF slot)
- Show weld history on the Android app as a scrollable list with charts
- Export as CSV

**Why it matters:** Transforms the welder from "I think that was a good weld" to "I **know** that was 4.2J at 0.15mm nickel = ✅ green"

**Effort:** Medium — needs ADC reads before/after pulse, SD card driver, new BLE message type for log sync, app UI

**Hardware needed:** None (SD card slot already on board)

---

### 2. 🔐 PIN/Password Lock for BLE

**Problem:** Anyone with a BLE scanner can connect and change parameters.

**Idea:**
- Extend existing OTA PIN auth to cover all BLE parameter writes
- Lock/unlock toggle configurable from the touchscreen
- PIN stored in NVS, changeable from settings
- Failed attempts → lockout timer

**Why it matters:** Essential in shared workshop environments

**Effort:** Low — auth flag already exists for OTA, just extend to params/commands

**Hardware needed:** None
[x] done
---

### 3. 📈 Temperature Monitoring (MOSFET / Supercap)

**Problem:** 2000A through 16 MOSFETs generates significant heat. No thermal protection.

**Idea:**
- Add **DS18B20** (1-Wire) or **NTC thermistor** on MOSFET heatsink → ADC on spare GPIO
- Optionally monitor supercap temperature (critical for lifetime)
- Show temperature on ESP32 dashboard + Android app
- **Thermal throttle:** refuse welding if MOSFET temp > 80°C
- Add thermal trend chart in app

**Available spare GPIO:** IO9 (ADC1_CH8) — IO15/IO17/IO18 are now used by the rotary encoder

**Why it matters:** Serious safety feature — prevents MOSFET thermal failure during rapid successive welds

**Effort:** Low — 1 sensor + 1 ADC read + UI update + new field in BLE status packet

**Hardware needed:** DS18B20 or NTC thermistor + pull-up resistor

---

### 4. 🌐 WiFi Mode for Advanced Features

**Problem:** BLE is limited to ~30KB/s and phone-only access.

**Idea:**
- **Web dashboard** — access from any device (tablet, laptop, PC) on the same network
- **WiFi OTA** — much faster firmware updates (500KB/s+ vs 30KB/s BLE)
- **Cloud logging** (optional) — upload weld history to a cloud service
- **AP mode** for initial setup (like IoT devices — connect to "MyWeld-XXXX" WiFi)
- WiFi and BLE can coexist on ESP32-S3, but BLE should remain the primary interface

**Why it matters:** Opens up advanced use cases without replacing the working BLE system

**Effort:** High — web server, mDNS, WiFi provisioning, dual-mode networking

**Hardware needed:** None (ESP32-S3 has WiFi built-in)

---

## ⚡ Tier 2: Quality-of-Life Improvements

### 5. 🔊 Custom Sound Profiles

**Problem:** Single set of beep/tone sounds for all users.

**Idea:**
- 3-4 built-in sound profiles: **Industrial** (sharp/metallic), **Arcade** (fun/8-bit), **Minimal** (subtle), **Silent**
- Different tones per event (beep, weld fire, error, ready, startup)
- Possibly load custom WAV/PCM files from SD card
- Profile selection in settings (ESP32 + Android)

**Effort:** Low-Medium — sound generation code already exists, just need alternate tone tables

**Hardware needed:** None

---

### 6. 📱 iOS Companion App (or Cross-Platform)

**Problem:** Currently Android-only. Many users have iPhones.

**Options:**
| Option | Pros | Cons |
|---|---|---|
| **Flutter** (Dart) | Single codebase, native BLE plugins | Rewrite all UI |
| **Kotlin Multiplatform** | Share business logic with existing Kotlin | Still need SwiftUI for iOS UI |
| **Web Bluetooth** (PWA) | Zero install, works on Chrome desktop too | Chrome-only, no iOS Safari support |
| **Native Swift** | Best iOS experience | Separate codebase to maintain |

**Recommendation:** Flutter or KMP for shared protocol/BLE layer, platform-specific UI

**Effort:** High — essentially building a second app (or rewriting in cross-platform)

---

### 7. ✅ Auto-Calibration Wizard (IMPLEMENTED)

**Problem:** Task 9 (ADC calibration wizard) is still pending. Manual calibration is tedious.

**Idea:**
- **Guided wizard on ESP32 touchscreen:**
  1. "Connect multimeter to supercap terminals"
  2. "Enter measured voltage: [___] V"
  3. Firmware calculates and stores correction factor
- **One-button recalibration** via Android app
- Store calibration constants + calibration date in NVS
- Show "⚠️ Calibration expired" if last cal was > 30 days ago
- Compare ADC reading vs reference → auto-compute multiplier

**Effort:** Medium — needs new UI screen, guided flow, NVS storage for cal date

**Hardware needed:** None (multimeter required by user for reference)

---

### 8. 📍 Electrode Wear Detection

**Problem:** Electrodes degrade over time, weld quality silently drops.

**Idea:**
- Track welding resistance trends over time (inferred from voltage drop patterns at similar charge levels)
- When weld energy delivery decreases for the same settings → alert
- "⚠️ Electrode resistance 40% higher than baseline — consider cleaning or replacing tips"
- Baseline established during first few welds with fresh electrodes

**Effort:** Medium — statistical analysis of weld history data, requires Tier 1.1 (weld quality scoring) first

**Hardware needed:** None (calculated from existing ADC data)

---

### 9. 🎯 Multi-Pulse Profiles (Advanced Pulse Sequences)

**Problem:** Current P1/T/P2 is a fixed dual-pulse. Some materials need more.

**Idea:**
- **3-pulse sequences:** P1/T1/P2/T2/P3 for thick materials or stainless steel
- **Ramp-up pulses:** Gradually increasing pulse width (P1 < P2 < P3) for sensitive materials
- **Electrode conditioning pulse:** Very short, low-energy pre-pulse to burn through oxide layers (aluminum)
- **Custom sequence builder** on Android app (drag-and-drop pulse blocks)

**Impact on firmware:**
- `generatePulse()` needs to be generalized to N pulses
- Preset structure grows (need array of pulse durations)
- BLE protocol needs updated PARAMS_WRITE for variable-length pulse data

**Effort:** Medium-High — significant firmware refactor, protocol extension, app UI

**Hardware needed:** None

---

## 🎨 Tier 3: Polish & Pro Features

### 10. 📊 Battery/Supercap Health Analytics

**Idea:**
- Track charge/discharge cycles over lifetime (NVS counter)
- **ESR estimation:** Measure voltage sag under load → estimate internal resistance increase
- Predict remaining supercap lifetime based on cycle count and ESR trend
- "Supercaps at ~80% health — consider replacement in ~6 months"
- Show health dashboard on Android app

**Effort:** Medium — needs consistent data collection over time

---

### 11. 🏷️ Material Database

**Idea:**
- Built-in searchable database of materials with recommended settings:
  - **Nickel strip:** 0.1mm, 0.15mm, 0.2mm, 0.3mm
  - **Stainless steel:** 0.1mm, 0.2mm
  - **Copper foil:** various thicknesses
  - **Aluminum:** with oxide-breaking recommendations
- Each entry includes: recommended P1/T/P2, electrode tip size, clamping force
- User can select material → auto-loads optimal settings
- Community contributions via GitHub JSON file

**Effort:** Low — mostly data entry + a new UI screen

---

### 12. 📲 Android Widget / Quick Settings Tile

**Idea:**
- **Home screen widget:** Connection status, supercap voltage %, last weld score
- **Quick Settings tile:** Tap to connect/disconnect BLE
- **Notification:** Persistent notification while connected showing voltage level

**Effort:** Medium — Android widget APIs, background BLE scanning

---

### 13. 🌙 Screensaver / Display Power Management

**Idea:**
- Dim display after X seconds of inactivity (configurable: 15s / 30s / 60s / never)
- Turn off display completely after X minutes (save power + extend display life)
- Wake on: touch, weld button press, BLE command
- Don't dim during active charging (show charging animation instead)
- Currently backlight is on GPIO1 with PWM — dimming is trivial

**Effort:** Low — timer + PWM fade, already have backlight control

---

### 14. 🧪 Test / Dry-Run Mode

**Idea:**
- Fire a "virtual weld" with OUTPUT_PIN disconnected (software-only timing)
- Show oscilloscope-style timing diagram on the display:
  ```
  P1 ██████░░░░░░░░████████████ P2
          ↑ T (pause) ↑
  ```
- Verify pulse timing without any welding hardware connected
- Useful for: setting up presets, teaching, debugging timing

**Effort:** Low — conditionally skip GPIO output, draw timing chart on LVGL

---
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

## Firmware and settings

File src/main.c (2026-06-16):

/**
 * MyWeld ESP32-S3 — Main Entry Point
 *
 * Supercap Spot Welder Controller
 * Multi-variant build: see board_config.h for active variant.
 *
 * Architecture:
 *   Core 0: Display UI rendering + BLE serial
 *   Core 1: Welding logic + ADC sampling + audio
 *
 * Safety: OUTPUT_PIN and CHARGER_EN are set to safe defaults
 *         BEFORE any other initialization.
 */

#include "driver/gpio.h"
#include "esp_log.h"
#include "esp_system.h"
#include "freertos/FreeRTOS.h"
#include "freertos/task.h"
#include "nvs_flash.h"
#include <stdio.h>
#include <string.h>

#include "board_config.h"
#include "audio_hal.h"
#include "ble_serial.h"
#include "config.h"
#include "display_hal.h"
#include "encoder.h"
#include "ota.h"
#include "settings.h"
#include "status_led.h"
#include "welding.h"


static const char *TAG = "MyWeld";

/**
 * Initialize GPIO pins to safe defaults.
 * MUST be called FIRST before any other init.
 */
static void gpio_init_safe_defaults(void) {
  // OUTPUT_PIN (MOSFET fire) → LOW immediately
  gpio_config_t output_conf = {
      .pin_bit_mask = (1ULL << PIN_OUTPUT),
      .mode = GPIO_MODE_OUTPUT,
      .pull_up_en = GPIO_PULLUP_DISABLE,
      .pull_down_en = GPIO_PULLDOWN_ENABLE,
      .intr_type = GPIO_INTR_DISABLE,
  };
  gpio_config(&output_conf);
  gpio_set_level(PIN_OUTPUT, 0);

  // CHARGER_EN → ON (charger enabled by default; polarity via CHARGER_CTRL_SSR)
  gpio_config_t charger_conf = {
      .pin_bit_mask = (1ULL << PIN_CHARGER_EN),
      .mode = GPIO_MODE_OUTPUT,
      .pull_up_en = GPIO_PULLUP_DISABLE,
      .pull_down_en = GPIO_PULLDOWN_ENABLE,
      .intr_type = GPIO_INTR_DISABLE,
  };
  gpio_config(&charger_conf);
  gpio_set_level(PIN_CHARGER_EN, CHARGER_GPIO_LEVEL_ON);

  // START_PIN (weld button) → input with pull-up
  gpio_config_t start_conf = {
      .pin_bit_mask = (1ULL << PIN_START),
      .mode = GPIO_MODE_INPUT,
      .pull_up_en = GPIO_PULLUP_ENABLE,
      .pull_down_en = GPIO_PULLDOWN_DISABLE,
      .intr_type = GPIO_INTR_DISABLE,
  };
  gpio_config(&start_conf);

  ESP_LOGI(TAG, "GPIO safe defaults initialized");
  ESP_LOGI(TAG, "  OUTPUT_PIN (IO%d) = LOW", PIN_OUTPUT);
  ESP_LOGI(TAG, "  CHARGER_EN (IO%d) = %s (charger ON, SSR=%d)",
           PIN_CHARGER_EN,
           CHARGER_GPIO_LEVEL_ON ? "HIGH" : "LOW",
           CHARGER_CTRL_SSR);
  ESP_LOGI(TAG, "  START_PIN  (IO%d) = INPUT_PULLUP", PIN_START);
}

/**
 * Initialize NVS (Non-Volatile Storage)
 */
static void nvs_init(void) {
  esp_err_t ret = nvs_flash_init();
  if (ret == ESP_ERR_NVS_NO_FREE_PAGES ||
      ret == ESP_ERR_NVS_NEW_VERSION_FOUND) {
    ESP_LOGW(TAG, "NVS partition truncated, erasing...");
    ESP_ERROR_CHECK(nvs_flash_erase());
    ret = nvs_flash_init();
  }
  ESP_ERROR_CHECK(ret);
  ESP_LOGI(TAG, "NVS initialized");
}

/**
 * Print boot banner
 */
static void print_banner(void) {
  printf("\n");
  printf("╔══════════════════════════════════════════╗\n");
  printf("║  ⚡ MyWeld ESP32-S3 Spot Welder v%s  ║\n", FW_VERSION_STRING);
  printf("║  Board: %-33s║\n", BOARD_NAME_STRING);
  printf("║  Built: %s %s              ║\n", FW_BUILD_DATE, FW_BUILD_TIME);
  printf("╚══════════════════════════════════════════╝\n");
  printf("\n");

  ESP_LOGI(TAG, "Free heap: %lu bytes",
           (unsigned long)esp_get_free_heap_size());
  ESP_LOGI(TAG, "Free PSRAM: %lu bytes",
           (unsigned long)heap_caps_get_free_size(MALLOC_CAP_SPIRAM));
}

void app_main(void) {
  // ========================================
  // PHASE 1: Safety-critical initialization
  // ========================================
  gpio_init_safe_defaults(); // MUST be first!

  // ========================================
  // PHASE 2: System initialization
  // ========================================
  nvs_init();
  print_banner();

  // Load saved settings from NVS
  settings_init();

  // Load ADC calibration from dedicated partition (survives factory reset)
  calibration_init();

  // OTA rollback check — mark firmware valid if we booted successfully
  ota_init();

  // ========================================
  // PHASE 3: Peripheral initialization
  // ========================================

#if HAS_LVGL
  // Silence IDF's internal lcd_panel.io.i2c error logger.
  // The AXS15231B touch controller does not ACK I2C when idle (no finger),
  // causing the IDF driver to log ESP_LOGE before returning the error to us.
  esp_log_level_set("lcd_panel.io.i2c", ESP_LOG_NONE);
#endif

  // Initialize audio (I2S or buzzer depending on variant)
  audio_init();

  // Initialize display (variant-specific: QSPI TFT, Nextion, or LCD)
#if HAS_LVGL
  display_init();   // QSPI TFT + LVGL init
#else
  display_hal_init();        // Nextion UART or I2C LCD init
  display_hal_show_splash(); // 2-phase boot splash (blocking)
#endif

  // Initialize rotary encoder (ISR + GPIO)
  encoder_init();

  // Initialize status LED (WS2812, DevKit only)
  status_led_init();
  status_led_set_event(LED_EVT_STARTUP);

  // ========================================
  // PHASE 4: Application initialization
  // ========================================

  // Build UI (variant-specific)
#if HAS_LVGL
  ui_init();   // Create LVGL widgets (includes splash screen)
#endif

  // Initialize welding state machine
  welding_init();

  // Initialize BLE serial
  ble_serial_init();

  // ========================================
  // PHASE 5: Start FreeRTOS tasks
  // ========================================

#if HAS_LVGL
  // Core 0: LVGL UI tick + rendering
  xTaskCreatePinnedToCore(ui_task, "ui_task", TASK_UI_STACK_SIZE, NULL,
                          TASK_UI_PRIORITY, NULL, TASK_UI_CORE);
#else
  // Core 0: Display update task (Nextion event polling / LCD refresh)
  display_hal_start_task();
#endif

  // Core 1: ADC voltage sampling
  xTaskCreatePinnedToCore(adc_task, "adc_task", TASK_ADC_STACK_SIZE, NULL,
                          TASK_ADC_PRIORITY, NULL, TASK_ADC_CORE);

  // Core 1: Welding state machine
  xTaskCreatePinnedToCore(welding_task, "welding_task", TASK_WELDING_STACK_SIZE,
                          NULL, TASK_WELDING_PRIORITY, NULL, TASK_WELDING_CORE);

  // Play startup sound
  audio_play_startup();

  // Start status LED animation task (DevKit only, compiles to no-op otherwise)
  status_led_start_task();

  // After startup animation, default to "charging" base state
  status_led_set_event(LED_EVT_CHARGING);

  ESP_LOGI(TAG, "All tasks started. MyWeld is ready! ⚡");
}

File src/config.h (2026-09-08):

#ifndef CONFIG_H
#define CONFIG_H

/**
 * MyWeld ESP32-S3 — Hardware Configuration
 * Boards: JC3248W535 (Guition, AXS15231B 480×320)
 *         JC4827W543 (Guition, NV3041A  480×272)
 * 
 * Original MyWeld V2.0 PRO designed by Aka Kasyan (YouTube)
 * https://www.youtube.com/@akakasyan
 * This project is an ESP32-S3 adaptation of his original Arduino Nano design.
 * Thank you Aka Kasyan for the inspiration and the excellent welding logic!
 * 
 * Pin assignments verified from official schematics and GPIO tables.
 */

#include "board_config.h"
#include <stdint.h>
#include <stdbool.h>

// ============================================================================
// GPIO Pin Definitions (VERIFIED from schematic + GPIO table)
// ============================================================================

// --- Welding Outputs ---
#ifndef PIN_OUTPUT
#define PIN_OUTPUT      GPIO_NUM_46  // MOSFET bank fire signal (P2 pin 6)
#endif
#ifndef PIN_CHARGER_EN
#define PIN_CHARGER_EN  GPIO_NUM_16  // Charger disconnect control (P2 pin 5)
#endif

// Charger disconnect hardware (set one):
//   CHARGER_CTRL_SSR=1 — DC SSR in series: GPIO HIGH = SSR ON = charging (OFF during pulse)
//   CHARGER_CTRL_SSR=0 — Buck module KEY via 2N2222: GPIO LOW = charging (legacy)
#ifndef CHARGER_CTRL_SSR
#define CHARGER_CTRL_SSR  1
#endif

#if CHARGER_CTRL_SSR
#define CHARGER_GPIO_LEVEL_ON   1
#define CHARGER_GPIO_LEVEL_OFF  0
#else
#define CHARGER_GPIO_LEVEL_ON   0
#define CHARGER_GPIO_LEVEL_OFF  1
#endif

// Use these instead of raw gpio_set_level(PIN_CHARGER_EN, …)
#define charger_gpio_enable()   gpio_set_level(PIN_CHARGER_EN, CHARGER_GPIO_LEVEL_ON)
#define charger_gpio_disable()  gpio_set_level(PIN_CHARGER_EN, CHARGER_GPIO_LEVEL_OFF)
#define charger_gpio_is_on()    (gpio_get_level(PIN_CHARGER_EN) == CHARGER_GPIO_LEVEL_ON)

// --- Physical Input ---
#ifndef PIN_START
#define PIN_START       GPIO_NUM_14  // External weld button, MAN mode (P2 pin 8)
#endif

// --- ADC Inputs (all ADC1 channels for reliability) ---
#ifndef PIN_VOLTAGE
#define PIN_VOLTAGE     GPIO_NUM_5   // Supercap voltage — ADC1_CH4 (P2 pin 1)
#endif
#ifndef PIN_PROTECTION
#define PIN_PROTECTION  GPIO_NUM_6   // Gate drive rail — ADC1_CH5 (P2 pin 2), safe up to ~25V
#endif
#ifndef PIN_CONTACT
#define PIN_CONTACT     GPIO_NUM_7   // Electrode contact detect — ADC1_CH6 (P2 pin 3)
#endif

// --- Display (QSPI — internal, no user wiring) ---
#define PIN_LCD_CLK     GPIO_NUM_47
#define PIN_LCD_CS      GPIO_NUM_45
#define PIN_LCD_TE      GPIO_NUM_38
#define PIN_LCD_BL      GPIO_NUM_1   // Backlight PWM
#define PIN_LCD_D0      GPIO_NUM_21
#define PIN_LCD_D1      GPIO_NUM_48
#define PIN_LCD_D2      GPIO_NUM_40
#define PIN_LCD_D3      GPIO_NUM_39

// --- Touch I2C ---
// JC3248W535: IO8=SCL, IO4=SDA, AXS15231B at 0x3B
// JC4827W543: IO4=SCL, IO8=SDA, GT911 at 0x5D (pins are swapped!)
#if (BOARD_VARIANT == BOARD_JC4827W543)
  #define PIN_TOUCH_SCL   GPIO_NUM_4   // SCL (from JC4827W543 schematic)
  #define PIN_TOUCH_SDA   GPIO_NUM_8   // SDA (from JC4827W543 schematic)
  #define TOUCH_I2C_ADDR  0x5D         // GT911 address (INT=LOW during reset)
  #define PIN_TOUCH_RST   GPIO_NUM_38  // GT911 reset pin
  #define PIN_TOUCH_INT   GPIO_NUM_3   // GT911 interrupt pin
#else
  #define PIN_TOUCH_SCL   GPIO_NUM_8   // SCL — confirmed from reference esp_bsp.h
  #define PIN_TOUCH_SDA   GPIO_NUM_4   // SDA — confirmed from reference esp_bsp.h
  #define TOUCH_I2C_ADDR  0x3B         // AXS15231B touch address
  #define PIN_TOUCH_RST   GPIO_NUM_NC  // No dedicated reset
  #define PIN_TOUCH_INT   GPIO_NUM_NC  // No dedicated interrupt
#endif

// --- I2S Audio (built-in amplifier → speaker on P6) ---
// Defaults for JC3248W535; board_config.h may override for DevKit variants
#ifndef PIN_I2S_LRCLK
#define PIN_I2S_LRCLK   GPIO_NUM_2   // I2S Word Select (WS)
#endif
#ifndef PIN_I2S_BCLK
#define PIN_I2S_BCLK    GPIO_NUM_42  // I2S Bit Clock
#endif
#ifndef PIN_I2S_DOUT
#define PIN_I2S_DOUT    GPIO_NUM_41  // I2S Data Out
#endif

// --- Rotary Encoder (KY-040 style, 5-pin module) ---
// Defaults for JC3248W535; board_config.h may override for DevKit variants
#ifndef PIN_ENC_S1
#define PIN_ENC_S1      GPIO_NUM_15  // CLK (quadrature A) — P2 pin 4
#endif
#ifndef PIN_ENC_S2
#define PIN_ENC_S2      GPIO_NUM_17  // DT  (quadrature B) — P3/P4
#endif
#ifndef PIN_ENC_KEY
#define PIN_ENC_KEY     GPIO_NUM_18  // SW  (push button, active LOW) — P3/P4
#endif

// --- Spare GPIOs (available for future expansion) ---
#ifndef PIN_SPARE_1
#define PIN_SPARE_1     GPIO_NUM_9   // P2 pin 7 (ADC1_CH8) — reserved for temp sensor
#endif
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

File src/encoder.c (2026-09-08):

/**
 * Rotary Encoder Driver — KY-040 compatible (Quadrature State Machine)
 *
 * Rotation: ISR fires on ANY edge of BOTH S1 (CLK) and S2 (DT).
 *           A Gray-code state machine tracks valid transitions only.
 *           One CW/CCW event is emitted per full detent (4 micro-steps).
 *           Contact bounce produces no false events because invalid
 *           state transitions (e.g. 11→00) are silently discarded.
 *
 * Button:   Polled in encoder_poll() with ENC_KEY_DEBOUNCE_MS debounce.
 *           Short press (<500ms) and long press (≥500ms) detection.
 *
 * Safety:   Runs entirely on Core 0. Cannot affect welding (Core 1).
 *           Cannot trigger a weld — only IO14 (physical button) can fire.
 */

#include "encoder.h"
#include "config.h"

#include "driver/gpio.h"
#include "esp_log.h"
#include "esp_timer.h"
#include "freertos/FreeRTOS.h"
#include "freertos/queue.h"

static const char *TAG = "ENCODER";

// ============================================================================
// Internal state
// ============================================================================

#define ENC_QUEUE_DEPTH 32

typedef struct {
    encoder_event_t evt;
    uint32_t interval_us;   // Time since previous detent (rotation only)
} enc_qitem_t;

static QueueHandle_t s_enc_queue = NULL;

// ----------------------------------------------------------------------------
// Quadrature state machine
//
// State = (S1_level | (S2_level << 1)), giving 4 possible values: 0–3.
// At rest (both pulled HIGH) the state is 3.
//
// Valid Gray-code sequences (KY-040 with mechanical detents):
//   CW  detent: 3 → 2 → 0 → 1 → 3  (4 micro-steps)
//   CCW detent: 3 → 1 → 0 → 2 → 3  (4 micro-steps)
//
// The lookup table is indexed by (old_state << 2 | new_state):
//   +1 = valid CW  micro-step
//   -1 = valid CCW micro-step
//    0 = no change  OR  invalid skip (bounce/noise) → ignored
//
// The accumulator counts valid micro-steps. Only when it reaches
// ±ENC_STEPS_PER_DETENT (4 on a KY-040) is a single CW/CCW event emitted.
// Remainder is kept so bounce leftover still counts toward the next detent.
// This makes the decoder inherently immune to contact bounce because:
//   - Bounce on one pin oscillates between two adjacent states (e.g. 3↔2),
//     producing +1 then -1, so the accumulator stays near zero.
//   - Electrical noise that skips a state (e.g. 3→0) produces 0 (invalid)
//     from the lookup table and is silently discarded.
// ----------------------------------------------------------------------------

static volatile uint8_t s_enc_state = 3;   // Rest: both pins HIGH (pull-up)
static volatile int8_t  s_enc_accum = 0;   // Micro-step accumulator
static volatile int64_t s_last_detent_us = 0;
static volatile int8_t  s_last_rot_dir = 0;  // +1 CW, -1 CCW
static uint32_t s_poll_interval_us = UINT32_MAX;

// Must live in DRAM for ISR access (not flash)
static const DRAM_ATTR int8_t s_quad_table[16] = {
//         new state →  0   1   2   3
/* old=0 (S1=0,S2=0) */ 0, +1, -1,  0,
/* old=1 (S1=1,S2=0) */-1,  0,  0, +1,
/* old=2 (S1=0,S2=1) */+1,  0,  0, -1,
/* old=3 (S1=1,S2=1) */ 0, -1, +1,  0,
};

// Button state machine
static volatile bool s_key_isr_flag = false;  // Set by ISR on falling edge
static bool    s_key_down       = false;   // Physical key state (debounced)
static int64_t s_key_press_ms   = 0;       // When debounced press started
static bool    s_long_sent      = false;   // Long-press event already emitted
static int64_t s_key_release_ms = 0;       // When release was first detected
static bool    s_key_releasing  = false;   // Release debounce in progress

// ============================================================================
// ISR handlers
// ============================================================================

// Quadrature ISR (shared handler for S1 and S2, fires on ANY edge)
static void IRAM_ATTR enc_quadrature_isr(void *arg)
{
    (void)arg;

    // Read current 2-bit state
    uint8_t new_state = (uint8_t)(gpio_get_level(PIN_ENC_S1)
                                | (gpio_get_level(PIN_ENC_S2) << 1));

    // Lookup direction from old→new transition
    uint8_t idx = (uint8_t)((s_enc_state << 2) | new_state);
    int8_t dir = s_quad_table[idx];

    s_enc_state = new_state;

    if (dir == 0) return;  // Invalid or no-change → ignore

    s_enc_accum += dir;

    // Full detent reached? Keep remainder (don't snap to 0).
    encoder_event_t evt = ENC_EVENT_CW;
    int8_t emit_dir = 0;
    if (s_enc_accum >= ENC_STEPS_PER_DETENT) {
        s_enc_accum = (int8_t)(s_enc_accum - ENC_STEPS_PER_DETENT);
        evt = ENC_EVENT_CW;
        emit_dir = 1;
    } else if (s_enc_accum <= -ENC_STEPS_PER_DETENT) {
        s_enc_accum = (int8_t)(s_enc_accum + ENC_STEPS_PER_DETENT);
        evt = ENC_EVENT_CCW;
        emit_dir = -1;
    }
    if (emit_dir == 0) return;

    int64_t now = esp_timer_get_time();
    uint32_t interval = UINT32_MAX;
    if (s_last_detent_us != 0 && emit_dir == s_last_rot_dir) {
        int64_t dt = now - s_last_detent_us;
        if (dt > 0 && dt < (int64_t)UINT32_MAX) {
            interval = (uint32_t)dt;
        }
    }
    s_last_detent_us = now;
    s_last_rot_dir = emit_dir;

    enc_qitem_t item;
    item.evt = evt;
    item.interval_us = interval;
    BaseType_t woken = pdFALSE;
    xQueueSendFromISR(s_enc_queue, &item, &woken);
    if (woken) portYIELD_FROM_ISR();
}

// Button ISR: fires on falling edge (button press, active LOW)
static void IRAM_ATTR enc_key_isr(void *arg)
{
    (void)arg;
    s_key_isr_flag = true;  // Latch — cleared by encoder_poll()
}

// ============================================================================
// Public API
// ============================================================================
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

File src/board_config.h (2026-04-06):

/**
 * MyWeld ESP32-S3 — Board & Variant Configuration
 *
 * Central hardware abstraction header. All variant-specific decisions
 * (display type, audio type, pin remapping) are resolved HERE based
 * on build-time defines set in platformio.ini.
 *
 * Build defines expected from platformio.ini:
 *   -DDISPLAY_TYPE=<n>   (1=QSPI TFT, 2=Nextion, 3=LCD 20×4, 4=COG 128×64)
 *   -DAUDIO_TYPE=<n>     (1=I2S, 2=LEDC Buzzer)
 *   -DBOARD_VARIANT=<n>  (1=JC3248W535, 2=DevKit, 3=GOOUUU CAM, 4=JC4827W543)
 */

#ifndef BOARD_CONFIG_H
#define BOARD_CONFIG_H

// ============================================================================
// Display type constants
// ============================================================================
#define DISPLAY_QSPI_TFT     1  // JC3248W535 built-in 480×320 QSPI (AXS15231B + LVGL)
#define DISPLAY_NEXTION       2  // Nextion HMI via UART (display handles UI rendering)
#define DISPLAY_LCD_2004      3  // 20×4 character LCD via I2C (HD44780 + PCF8574)
#define DISPLAY_COG_12864     4  // 128×64 graphic COG LCD via I2C (ST7567S)

// ============================================================================
// Audio type constants
// ============================================================================
#define AUDIO_I2S             1  // I2S DAC → amplifier → speaker (JC3248W535 built-in)
#define AUDIO_BUZZER          2  // Passive buzzer via LEDC PWM (any GPIO)

// ============================================================================
// Board variant constants
// ============================================================================
#define BOARD_JC3248W535      1  // Guition JC3248W535 all-in-one (display+touch+speaker)
#define BOARD_DEVKIT           2  // Generic ESP32-S3 N16R8 DevKit-C
#define BOARD_GOOUUU_CAM       3  // GOOUUU ESP32-S3-CAM N16R8 (camera NOT connected)
#define BOARD_JC4827W543       4  // Guition JC4827W543 4.3" 480×272 (NV3041A+GT911+speaker)

// ============================================================================
// Defaults (if not set by platformio.ini — fallback to current board)
// ============================================================================
#ifndef DISPLAY_TYPE
#define DISPLAY_TYPE   DISPLAY_QSPI_TFT
#endif

#ifndef AUDIO_TYPE
#define AUDIO_TYPE     AUDIO_I2S
#endif

#ifndef BOARD_VARIANT
#define BOARD_VARIANT  BOARD_JC3248W535
#endif

// ============================================================================
// Feature flags (derived from variant selection)
// ============================================================================

// Does this variant use LVGL for graphical UI?
#if (DISPLAY_TYPE == DISPLAY_QSPI_TFT)
  #define HAS_LVGL           1
  #define HAS_TOUCH          1
  #define HAS_BACKLIGHT      1
#else
  #define HAS_LVGL           0
  #define HAS_TOUCH          0
  #define HAS_BACKLIGHT      0
#endif

// Does this variant use Nextion HMI?
#if (DISPLAY_TYPE == DISPLAY_NEXTION)
  #define HAS_NEXTION        1
#else
  #define HAS_NEXTION        0
#endif

// Does this variant use a character LCD?
#if (DISPLAY_TYPE == DISPLAY_LCD_2004)
  #define HAS_CHAR_LCD       1
#else
  #define HAS_CHAR_LCD       0
#endif

// Does this variant use a 128×64 COG graphic LCD?
#if (DISPLAY_TYPE == DISPLAY_COG_12864)
  #define HAS_COG_LCD        1
#else
  #define HAS_COG_LCD        0
#endif

// Audio backend
#if (AUDIO_TYPE == AUDIO_I2S)
  #define HAS_I2S_AUDIO      1
  #define HAS_BUZZER         0
#elif (AUDIO_TYPE == AUDIO_BUZZER)
  #define HAS_I2S_AUDIO      0
  #define HAS_BUZZER         1
#else
  #error "AUDIO_TYPE must be AUDIO_I2S (1) or AUDIO_BUZZER (2)"
#endif

// Onboard RGB LED (WS2812 NeoPixel)
// The ESP32-S3-DevKitC-1 has a WS2812 on GPIO48.
// The JC3248W535 uses GPIO48 for PIN_LCD_D1 — no RGB LED available.
#if (BOARD_VARIANT == BOARD_DEVKIT)
  #define HAS_RGB_LED        1
#else
  #define HAS_RGB_LED        0
#endif

// ============================================================================
// Pin Definitions — DevKit variant overrides
// ============================================================================
// For the JC3248W535, pins are fixed by the board design (see config.h).
// For the generic DevKit, we remap display/audio pins to user-accessible GPIOs.
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

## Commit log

2026-03-14 feat: initial commit - MyWeld ESP32 firmware
    - Dual-core ESP32-S3 spot welder firmware
    - Binary BLE protocol with preset management
    - Welding state machine with safety interlocks
    - LVGL touch UI with rotary encoder navigation
    - Dynamic P3/P4 parameter display
    - MAN/AUTO trigger modes
    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
    [MyWeld-ESP32.PrjPcb, Sheet1.SchDoc, esp32-jc3248W535.SchLib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]
2026-03-15 fix: disable encoder during OTA, fix BLE pulse validation
    [ble_serial.c, config.h, ui.c]
2026-03-15 fix: update ADC calibration values and sdkconfig
    [settings.c]
2026-03-18 fix: OTA stability, I2S audio support, LCD2004 layout improvements
    - Fix OTA crash: use OTA_SIZE_UNKNOWN to avoid blocking flash erase
    - Fix OTA UI: use dirty-flag mechanism to prevent I2C conflicts during OTA
    - Add I2S audio support for DevKit (MAX98357 on GPIO 11/12/13)
    - Remove buzzer support, switch AUDIO_TYPE to I2S for DevKit envs
    - Fix I2S pin redefinition warnings with #ifndef guards in config.h
    - Fix LCD S delay display: show decimal (%.1f) instead of integer
    - Rearrange LCD2004 layout: AUTO/MAN moved to Row 3 for clarity
    - Add multi-board support: lcd1604, lcd2004, nextion display drivers
    - Add board_config.h for DevKit pin overrides
    [Sheet1-ascii.SchDoc, Sheet1.SchDoc]
2026-03-19 feat: hardware compatibility descriptor, OTA variant matching, LCD2004 encoder navigation
    - Add hw_descriptor.c/h for compile-time hardware variant identification
    - Update BLE protocol to transmit hwCompatId during OTA handshake
    - Add board_config.h multi-variant support with pinout definitions
    - Implement LCD2004 rotary encoder parameter navigation and editing
    - Add devkit-lcd2004-pinout.md documentation
    - Update CMakeLists.txt with new source files
    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
2026-03-23 feat: add RGB status LED, LCD settings menu, and dashboard modes
    - Add WS2812 RGB status LED driver (status_led.c/h) with event-driven color feedback
    - Integrate LED hooks into welding, BLE, and OTA modules
    - Fix onboard LED GPIO pin (GPIO48) for N8R2/N16R8 clone boards (requires solder bridge)
    - Add LCD 2004 settings menu with encoder long-press access
    - Implement User Defined (UD) and Preset (PR) dashboard display modes
    - Add preset cycling and display logic for PR mode
    - Update board_config.h with RGB LED pin and build config
    - Update CMakeLists.txt to include status_led in build
    - Update schematic (easyeda project file)
    [ble_serial.c, board_config.h, config.h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]
2026-03-25 feat(display): add ST7567S 128x64 COG graphic LCD driver (DISPLAY_TYPE=4)
    - New framebuffer-based driver with dirty-page tracking (1KB FB)
    - I2C bus scan for auto-detecting display address
    - Built-in 5x7 font + 2x large text for status line
    - Graphical dashboard: voltage bar, charge graph, pulse params
    - Encoder navigation with blink cursor + edit mode
    - Settings screen (volume, sound, preset selection)
    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
2026-03-26 feat(ui): add 2-phase boot splash screen across all display variants
    - Phase 1: 'Welcome' centered (1.5s)
    - Phase 2: App name + version + credits (1.5s)
    - All messages configurable via SPLASH_MSG_* defines in config.h
    Display implementations:
    - LVGL (QSPI TFT): animated scr_splash with fade-in transition to dashboard
    - LCD 2004: centered text on 20x4 character LCD
    - LCD 1604: centered text on 16x4 character LCD
    - ST7567S COG: large/normal text centered on 128x64 framebuffer
    - Nextion: text sent to tTitle/tSub HMI objects
    Also fixes:
    - PIN_I2S_BCLK/LRCLK/DOUT redefinition warnings in board_config.h
    (added #undef before DevKit overrides)
    [board_config.h, config.h, lcd1604.c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]
2026-03-28 docs: update schematics to IR4427/TLP358 gate drivers, migrate to EasyEDA
    - Replace old Altium schematic (Schematic.jpg) with two EasyEDA variants:
    - IR4427PBF half-bridge gate driver
    - TLP358H(F) photocoupler gate driver (galvanic isolation)
    - Update README, circuit-diagram, adaptation docs to match new schematics
    - Remove circuit-schematics.html (replaced by EasyEDA project)
    - Remove old Altium project files (.SchDoc, .SchLib, .PrjPcb, etc.)
    - Update BOM: gate resistors 4R7→2R2, TVS 1.SKE12CA→1.5KE12A
    - Add variant comparison table to circuit-diagram.md
    [MyWeld-ESP32.PrjPcb, Sheet1-ascii.SchDoc, Sheet1.SchDoc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]
2026-03-30 v1.0.4: Boost 0.15mm preset, factory preset immutability, auto-version, OTA LCD fix
    - Boost 0.15mm Nickel preset (P1:5→6, T:20→22, P2:8→10) for stronger welds on 18650 negative terminal
    - Factory presets (0-6) now always load from firmware code, not NVS — FW updates take effect without factory reset
    - Factory preset slots are now write-protected (settings_save_preset rejects index < 7)
    - Auto-increment FW_VERSION_PATCH on every build via name_firmware.py
    - Firmware output named MyWeld_<env>_v<version>.bin
    - Fix OTA LCD garbage: skip encoder/blink/settings during OTA, only redraw on progress change
    - Suppress ADC/state dirty flags during OTA overlay to prevent flicker
    [config.h, lcd2004.c, settings.c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]
2026-04-06 feat: add JC4827W543 board support (4.3in 480x272 NV3041A + GT911)
    - NV3041A QSPI panel driver (esp_lcd_nv3041a.c/h)
    - GT911 capacitive touch controller (I2C, addr 0x5D)
    - Native landscape pipeline (direct flush, no SW rotation)
    - 4MB flash config: partitions_4mb.csv, sdkconfig.defaults.jc4827w543
    - LVGL Helium/NEON ASM exclusion script (fix_lvgl_asm.py)
    - UI layout constants derived from DISPLAY_HEIGHT for 480x272 adaptation
    - Board variant BOARD_JC4827W543 (id=4) in board_config.h
    - Build: pio run -e jc4827w543
    [partitions_4mb.csv]
2026-04-07 fix: card body tap no longer increments pulse/delay values - only +/- buttons change values now (v1.0.52)
    [config.h, display.c, esp_lcd_nv3041a.c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]
2026-06-11 feat: add TTS voice prompts for boot and BLE pairing lifecycle
    Spoken welcome, ready-to-pair, pairing, and connected prompts on I2S boards
    with buzzer fallbacks, weld charge warnings, and README/docs for all variants.
    [audio.c, ble_serial.c, buzzer.c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]
2026-06-16 feat: add SSR charger disconnect polarity (v1.0.68)
    Introduce CHARGER_CTRL_SSR and charger_gpio_* helpers so GPIO HIGH keeps the SSR on while charging and LOW opens it during weld pulses. Legacy 2N2222 KEY control remains available with CHARGER_CTRL_S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
2026-09-08 feat: 1ms wheels, V/max charge %, and T=OFF pulse-chain clamp
    Ignore ESR sag after a pulse, speed up the encoder, and force P2/P3/P4 to OFF on the welder when T is 0.
    [ble_serial.c, config.h, encoder.c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]
